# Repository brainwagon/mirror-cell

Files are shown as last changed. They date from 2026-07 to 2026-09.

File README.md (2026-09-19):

# Mirror Cell — 6" and 8"

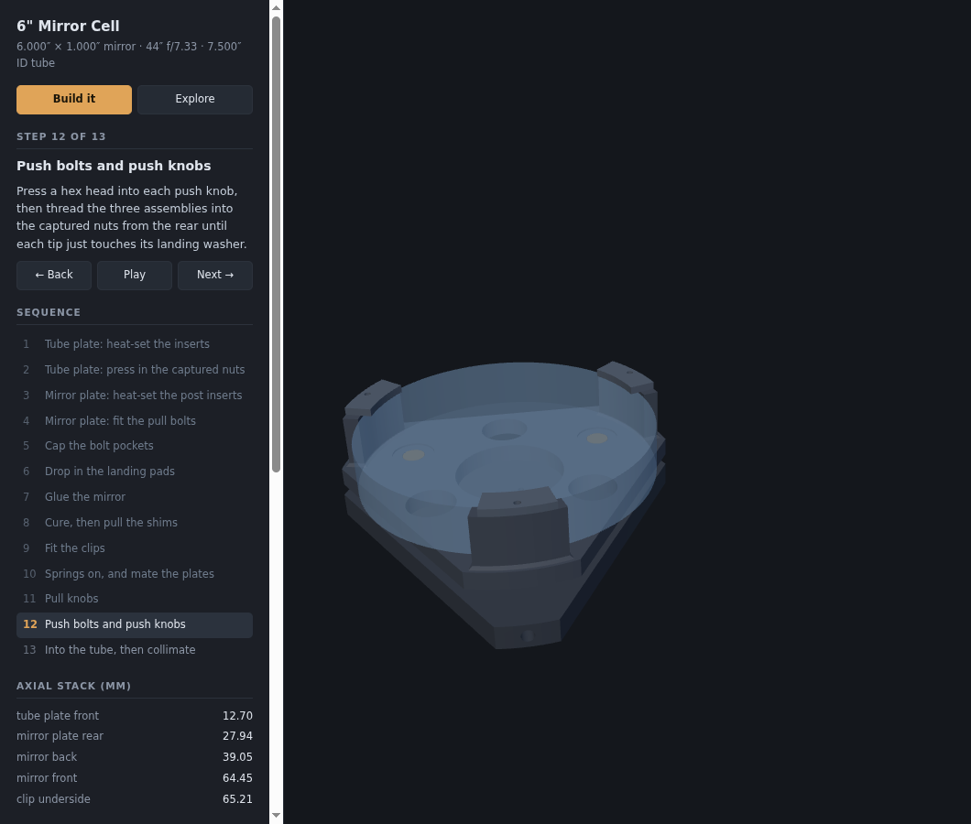
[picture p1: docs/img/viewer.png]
The assembly viewer, at step 12 of the 6" build sequence


A 3-point primary mirror cell — 3D printed in black ABS, assembled with 10-24 hardware by
default. The six collimation bolts (push and pull) can instead be **1/4-20** with
`--bolts 1/4-20`; the three tube-mount inserts stay 10-24 either way (see
[ADR-0004](./docs/adr/0004-collimation-hardware-is-a-config-option.md)). Two telescopes are
built from one model:

| | Mirror | Tube ID | Build | Buy list |
|---|---|---|---|---|
| **6"** (default) | 6.000" × 1.000", f/7.33 | 7.500" | `build/` | `BOM.md` |
| **8"** | 8.000" × 1.330" | 10.000" | `build-8/` | `BOM-8.md` |

The 6" is the original and the only one that has been printed and measured. The 8" is the
same cell with three numbers changed — see
[ADR-0003](./docs/adr/0003-the-8-inch-cell-is-the-same-cell-parameterised.md) for what
scales, what deliberately does not, and why it stops at two entries.

| File | Purpose |
|---|---|
| `HANDOFF.md` | **Start here when resuming** — state, blockers, and the traps |
| `BOM.md`, `BOM-8.md` | The buy lists, annotated. Generated — `--check` fails if one goes stale |
| `CONTEXT.md` | Glossary. Tube plate, Mirror plate, Station, Support point, Silicone dab, … |
| `mirror-cell-spec.md` | The design, its numbers, and the reasoning behind them (written for the 6") |
| `docs/adr/0001-…md` | Why the support points sit at 0.75R rather than the PLOP optimum |
| `docs/adr/0002-…md` | Why both rear controls are printed knobs clearing each other radially |
| `docs/adr/0003-…md` | Why the 8" cell is a config entry rather than a second design |
| `mirror_cell.py` | The model. All dimensions are named variables at the top |
| `test_coupon.py` | The ABS test coupons — the print that dials `FIT` |
| `TEST-COUPON.md` | How to print them, how to read them, where the answer goes |
| `index.html` | Assembly viewer — assembled/exploded, in the browser |
| `90866A011_….STEP` | Vendor wing-nut solid (McMaster). No longer part of the design — kept as ADR-0002's evidence |

## Build the geometry

```sh
python3 mirror_cell.py                # the 6" cell  -> build/,   BOM.md
python3 mirror_cell.py --aperture 8   # the 8" cell  -> build-8/, BOM-8.md
python3 mirror_cell.py --bolts 1/4-20 # 1/4-20 collimation bolts -> build-6-q20/
```

Runs 177 assertions **for the cell selected**, then writes `*.step`, `*.stl`, `3mf/*.3mf`
(geometry **and** that part's slicer settings), one dated zip of every part's STEP and
3MF — `mirror-cell-6in-YYYY-MM-DD.zip` — `assembly.json` and the bill of materials
— `bom.md`, `bom.csv`, and the committed snapshot at the top level (the build directories
are gitignored, so those snapshots are the copies the repo carries). If a BOM row changed,
the snapshot is rewritten and the run says which rows moved — **commit it**. To check
without writing anything:

```sh
python3 mirror_cell.py --check
python3 mirror_cell.py --aperture 8 --check
```

which verifies and then *refuses* a stale snapshot instead of repairing it. That is the CI
entry point, and the one to run on a fresh checkout — **run it for both apertures**, since
each one only checks the cell it was asked for.
The assertions encode the spec — the three gaps that must never close, both fastener
bearing floors, assembly clearances, spring travel, post placement, and printer bed fit.
**If a check fails, the geometry is wrong; do not print it.** Several real defects were
caught this way rather than at the print bed — including a version whose mirror could
never have been installed, because the clips were printed onto the posts.

If your blank is not the thickness the cell assumes (1.000" at 6", 1.330" at 8"), give it
in inches:

```sh
python3 mirror_cell.py --aperture 8 --mirror-thickness 1.375   # -> build-8-t1.375/
```

Everything that follows from the glass follows it — post height, the tube stub, the moving
mass the preload check weighs. A variant builds into its own directory, viewable as
`?cell=8-t1.375`, and writes no committed BOM snapshot, so the verified cells are never
touched. It is **refused** if the blank is floppier than the ones the 0.75R support
argument covers ([ADR-0003](./docs/adr/0003-the-8-inch-cell-is-the-same-cell-parameterised.md)):
an 8" blank 1" thick fails, at 3.16× the 6" cell's sag against the 1.34× argued for.

If you have 1/4-20 hardware instead of 10-24 for the collimation bolts:

```sh
python3 mirror_cell.py --bolts 1/4-20            # -> build-6-q20/
python3 mirror_cell.py --aperture 8 --bolts 1/4-20   # -> build-8-q20/
```

Only the six push/pull bolts, their six nuts, their pockets and holes change; the knobs and
the mirror plate grow to suit the larger hexes and the taller head, the springs open to
10.5 mm OD (with a longer free length to hold the preload) so they clear the 6.35 mm shank
([ADR-0005](./docs/adr/0005-the-1-4-20-cell-uses-a-larger-bore-spring.md)), and the
tube-mount inserts stay 10-24. It is a variant, so it builds into its own directory
(viewable as `?cell=6-q20`) and writes no committed BOM snapshot. **`FIT_PRESS` is measured
for 10-24 only** and is proportionally tighter on the larger 1/4-20 hex, so the fit coupon
refuses `--bolts 1/4-20` — measure a 1/4-20 pocket before printing the cell
([ADR-0004](./docs/adr/0004-collimation-hardware-is-a-config-option.md)).

Requires `build123d` (`pip install --user build123d`).

## View it

It is live at **<http://mvandewettering.com/mirror-cell/>** — the 6" cell, or
[`?cell=8`](http://mvandewettering.com/mirror-cell/?cell=8) for the 8". GitHub Actions
runs the exporter for both apertures **and both bolt sizes** on every push to `main` and
publishes the result (`.github/workflows/pages.yml`), because the build directories are
gitignored and so the site cannot be served from the repo as committed.

A **Mirror** switch (6″/8″) and a **Collimation bolts** switch (10-24/1/4-20) at the top of
the panel move between builds without leaving the page — each navigates to the matching
`?cell=` directory and keeps your place in the sequence. The mirror switch drops any
`--mirror-thickness` suffix (a blank is particular to its aperture); the bolt size carries
across. Both states are confirmed against `assembly.json`, so the switches always agree with
the geometry on screen.

To view a local build instead: the page fetches STLs, so it needs to be served over
HTTP — `file://` will not work.

```sh
python3 -m http.server 8018
# then open http://localhost:8018/              the 6" cell
#           http://localhost:8018/?cell=8       the 8" cell
#           http://localhost:8018/?cell=6-q20   the 6" cell, 1/4-20 collimation bolts
```

`?cell=8` reads `build-8/` instead of `build/`, and `?cell=6-q20` reads `build-6-q20/`, so
run the exporter for that combination first or the page has nothing to fetch. The coupons
are shared and always come from `build/`.

Two modes:

- **Build it** — steps through the 13-stage assembly sequence. Parts fly in as they are
  fitted, the mirror-plate sub-assembly is held clear while it is worked on, and the
  shims come back out at step 8. Each step carries its instructions, and the
  order-critical ones carry a caution. Prev/Next, a Play button, ←/→ keys, and a
  clickable step list. Linkable as `#step=7`.
- **Explore** — the explode slider and per-part visibility toggles.

The last step drops the cell into a **transparent stub of the sonotube** (7.750″ OD,
0.125″ wall, reaching 3.65″ behind the tube plate and 2″ above the mirror) with a 40 mm
fan on the rear face, so the finished assembly can be seen in context. Both are display
only and can be switched off in Explore. **The fan is a stand-in drawn in `fan()`,
not a vendor solid** — trust its envelope, not its details.

Under both is a **Downloads** panel. First **All printed parts**, one zip holding every
part's STEP and 3MF — named for the cell and the day it was built,
`mirror-cell-6in-2026-09-15.zip`, because once it has been mailed to somebody the filename
is all that says which cell it holds and how old it is. Its contents are taken from the
same download list the rows below it are drawn from, so it cannot quietly hold a different
set; the exporter writes it after the 3MFs have been verified and sweeps the cell's older
zips as it goes. Then the **annotated bill of materials** — MD or
CSV — which is not a hand-maintained table: `bom()` in `mirror_cell.py` counts the printed
quantities off the same instance lists the picture uses, reads every hardware dimension
out of the parameters, and carries one line of *why* for each row (machine screws not cap
screws, springs by geometry not by rate, fender washers on the outside). Assertions check
that it lists every printed part, agrees with the download list part for part, buys
exactly the nuts, washers, springs and screws the model draws, and leaves no row
unannotated. Below it is every printed part and both test coupons, each with its STEP, its
**3MF** and (smaller) its STL. The 3MF is the one to print: a solid in real units that
also carries that part's walls, top/bottom shells and infill, so it slices without being
dialled in. They ride as **per-object overrides** in `Metadata/model_settings.config`, an
Orca/Bambu-family convention rather than anything in the 3MF standard — the core spec has
no notion of a perimeter count — so in Cura and friends the file opens as plain geometry
and the settings are ignored. **Select your own process preset first**, at 0.2 mm layers:
the overrides sit on top of it and move only the part-specific keys, so your speeds,
accelerations and temperatures are the ones you chose, and they survive switching presets.
Layer height is deliberately *not* in the file — it has no per-object form, and the shell
counts are layer counts that only buy the intended thickness at 0.2 mm. `verify()` checks the settings data, and after writing, each
file is reopened and its config compared with what the model meant, because seven files
with no settings in them look exactly like seven correct ones from the outside. That list
is generated — printed parts from `assembly.json`, coupons from `coupons.json` — so it
cannot offer a file the exporter does not write, and an assertion checks that it names
every part in `PARTS` with the right quantity. The coupon rows appear once `test_coupon.py` has been
run; until then the panel says so. `build/` is gitignored, so the files are whatever your
last run produced.

Drag to orbit, scroll to zoom, right-drag to pan. The picture at the top of this file is
that page, on step 12 of the 6" sequence.

**The instructions are not written in the HTML.** `sequence()` in `mirror_cell.py` emits
them alongside the geometry, and assertions check that every step names a part that
actually exists and that the last step shows the finished cell. Instructions and parts
cannot drift apart.

three.js is vendored under `js/vendor/` (copied from `~/dob`); there is no CDN or network
dependency, and no STL loader — `parseSTL` reads build123d's binary STLs directly.

## One source of truth

Every position in the viewer comes from the selected cell's `assembly.json`, which
`mirror_cell.py` writes from the same variables that cut the geometry. No dimension is
typed into the JavaScript, so the picture cannot drift away from the parts — and the
same page draws either cell without knowing anything about apertures.

## Status

No cell part has been printed yet, but **both coupons have.** The fit coupon (2026-07-28)
gave 0.7–0.9 % measured shrink and put the captured nut on the 0.10 rung, so
`FIT_PRESS = 0.10`. The insert coupon (2026-07-29) passed on both 10-24 bores, the 3.05 mm
roof and the M3 bores in the rib, with the `insert_solid` modifiers in place —
`INSERT_BORE_D = 6.5` stands as drawn. **The tube plate is cleared to print.**

The mirror plate still waits on `FIT_SLIP = 0.20`, which is predicted from the shrink
rather than measured — one 10-24 hex bolt in row H of the coupon settles it. And the insert
coupon has not been *sectioned*, which is the only way to confirm the modifier put solid
material around the bore in the plastic rather than only in the file. See
[TEST-COUPON.md](./TEST-COUPON.md).

The rear end was reworked afterwards ([ADR-0002](./docs/adr/0002-both-rear-controls-are-printed-knobs.md)):
both controls are printed knobs that clear each other radially, the wing nut is gone, and
all six bolts are 10-24 × 1½″ machine screws by default — the same six can be 1/4-20 with
`--bolts 1/4-20` ([ADR-0004](./docs/adr/0004-collimation-hardware-is-a-config-option.md)),
which grows the knobs to Ø19.5 and the mirror plate to 10.1 mm. Print one pull knob and
press a nut into its 2.2 mm wall before committing to six. Plate and knob outlines are
functional but aesthetically provisional.

**Nothing of the 8″ cell has been printed at all.** Its 177 checks pass and it shares the
6″ cell's measured fits, so the coupon work carries over — but its tube plate is
237 × 207 mm on a 250 mm bed with only a 5 mm brim, and warp on a plate that size is the
one risk no assertion covers. Print that plate first.

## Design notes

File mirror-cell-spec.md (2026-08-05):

# 6" Mirror Cell — Design Spec

*Derived from a grilling session, 2026-07-28. This is the design for one specific
telescope: the 6" Newtonian originally built in the 1970s, being rebuilt with a 3D-printed
cell. Every number below is that cell's.*

*An **8.000" × 1.330"** variant was added later and is built from the same model by
`--aperture 8`. It is the same architecture, the same hardware and the same assertions,
with the mirror, tube, bolt circles, plate outlines and spring following from three
numbers — the derivation and its limits are in
[ADR-0003](./docs/adr/0003-the-8-inch-cell-is-the-same-cell-parameterised.md), and that is
where to look before assuming any figure on this page applies to it. What still holds for
both: §3 architecture, §5 the nominal-dimension convention, §6 compression everywhere, and
every tripwire in §11.*

Terminology is defined in [CONTEXT.md](./CONTEXT.md) and used strictly here.

---

## 1. The telescope this is for

| | |
|---|---|
| Mirror | 6.000" dia × 1.000" thick, 44" focal length (**f/7.33**), **2.3 lb** |
| Tube | Sonotube, 7.750" OD / **7.500" ID** |
| Related | `~/dob` (mount designer), `~/dob-6-project` (this scope's DXFs), `~/blip` (the FEA that settled the support radius) |

The mount project `~/dob` explicitly scopes out the mirror cell — its part inventory has no
cell at all. This project fills that hole.

## 2. Scope

**In scope**, all five jobs of a cell: axial support, lateral support, retention,
collimation, and the tube interface.

**Out of scope:** optical design (settled — 44" f/7.33); the mount (that's `~/dob`); any
aperture beyond the two the model builds. A 3-point cell is only valid to roughly 8–10",
so the 8" variant sits at the top of the range and **nothing larger belongs in this file** —
bigger mirrors need 6- or 9-point flotation, which is a different part family. A thin blank
is out of scope at *any* diameter: both cells' support radius depends on a full-thickness
mirror (§11, ADR-0001, ADR-0003).

## 3. Architecture

Two plates and three Stations.

- **Tube plate** — fixed to the sonotube, carries the collimation hardware, never touches
  the mirror.
- **Mirror plate** — floats on the collimation hardware, carries the mirror.
- **Station** — one of three positions at 90°/210°/330°. Each carries a Push bolt, a Pull
  bolt, a Support point, a Centering post and a Side clip, **all on one ray from the axis.**

Collimation is **push-pull with springs on the pull bolts** — the springs give compliance
while adjusting, the push bolts lock. This follows
[Stellafane](https://stellafane.org/tm/dob/ota/cell2.html) and matches the existing cell.

## 4. Geometry

**Radii.** Push bolts at **r = 1.500"**. Pull bolts at **r = 2.250" (0.75R)**. The three
Support points are **coaxial with the pull bolts** — see [ADR-0001](./docs/adr/0001-support-points-coaxial-with-pull-bolts.md).

**Axial stack**, measured from the Tube plate's rear face:

```
0.0000  tube plate rear face   ← both knobs live here
0.5000  tube plate front face
        ── 0.600" nominal spring gap ──
1.1000  mirror plate rear face  ← landing pads here
1.4750  mirror plate front face ← RTV wells here
1.5375  mirror back             (0.0625" bond)
2.5375  mirror front
2.5675  clip underside          (0.030" air gap)
```

The 0.600" gap is a **nominal, not a fixed dimension** — the Pull knobs set the real value.
The spring must neither coil-bind at minimum gap nor go slack at maximum. It cannot reach
either: the pull bolt's thread runs out **3.41 mm** past nominal, and the spring does not
go slack until **3.76 mm**, so the mechanism stops while the spring is still doing its job.
The push side has to follow the pull side anywhere it can go — at the widest reachable gap
the Push knob still stands **6.75 mm** off the plate rather than bottoming against it.

## 5. Parts

### Tube plate
7.500" OD triangle with three arc corners, flats at **60 mm** from the axis,
**0.500" thick**.

The flats are cut deep — 205 cm³ against 313 cm³ for a lightly-trimmed triangle, a **35%
saving on the largest part in the design**. That is safe because **the load path never
crosses a flat**: the collimation bolts sit on the station rays at r = 1.500" and 2.250",
and the tube screws are on those *same* rays at the arc corners, so the mirror's weight
travels radially outward along each arm. Material between stations carries torsion only,
and at ½" thick against ~2 lb per Station there is enormous margin. It also opens the back
of the cell further for mirror cooldown (§3) and leaves less large flat area to warp.

**The binding constraint is the corner tabs, not stiffness.** Those tabs carry the three
radial insert bores from which the entire cell hangs; a tab is
`2·(TP_FLAT_D − R/2)/cos 30°` wide at the rim, so cutting past ~53 mm eats into the bores.
At 60 mm the tab is 28.6 mm wide, leaving 11 mm of ABS each side.

- **Draw the OD at nominal 7.500"** and let ABS shrinkage supply the clearance. This is
  empirically confirmed by a test-fitted print, not calculated. **Do not pre-compensate
  any tube-referenced dimension** — mixing nominal and compensated conventions in one part
  is how this gets ruined.
- Center bore **1.500"** (changed from the prototype's 1.622" — see below), plus four M3
  holes on a 32 mm square: a **40 mm fan option, left unpopulated**. These cost nothing
  now and cannot be added later without pulling the mirror and reprinting.

  > **Changed from the prototype.** A 40 mm fan's screws sit on a 32 mm square, i.e. at
  > r = 22.63". Against a 1.622" bore that leaves a **0.43 mm web** — not a printable
  > feature. 1.500" restores a 1.98 mm web while still passing nearly the fan's full
  > 38 mm throat. Caught by the model's checks, not by inspection.
- Three **radial** 6.5 mm heat-set insert bores at mid-thickness, at the Stations.
- Push-bolt **hex nut pockets at r = 1.500", opening forward** (see §6).
- Pull-bolt clearance holes at r = 2.250", with spring seats on the front face.
- The prototype's six 0.5" edge scallops are **dropped**.

### Mirror plate
Triangle with three arc corners at **88.0 mm** radius, **0.375" thick**.

The outline is set by what it must contain, not by the tube. It has to hold the posts
(outer face at 84.96 mm) **plus the room their root chamfer needs outboard** — 3.04 mm of
margin. It was briefly trimmed to 86.0 to save material; that saved 1.7% and capped the
chamfer at 1.04 mm on the face that needs it most, so it went back to 88.0. Cheap plastic,
expensive stress riser.

Against a 95.25 mm tube-wall radius that is **6.9 mm of clearance at 3° of tilt**, and the
governing feature changes with angle: below ~5° the plate rim dominates, above it the clip
tops do, because tilt trades `r·cosθ` against `h·sinθ`.

- Pull-bolt **hex pockets at r = 2.250", opening forward, capped** (see below).
- **RTV wells** (22 mm dia) around each pocket to meter glue volume.
- **Landing-pad recesses** for **#4** washers on the rear face at r = 1.500". A #4 under a
  #10 bolt — see §7, the bore is the point.
- Centre bore **56 mm** — its *own* parameter, not the tube plate's. The tube plate's bore
  is set by the 40 mm fan screw circle; this one is limited by the landing pads (recess
  inner edge at 34.0 mm) and wants to be as open as possible so fan air actually reaches
  the back of the glass. Coupling the two would tie together constraints that have nothing
  to do with each other.
- Three **lightening holes** (r = 12.5 mm) at the mid-angles, between Stations.
- Three **Centering posts**, inner face at r = 3.030", 8 mm thick, each with an **M3
  heat-set insert** in its top face for a clip.
- A **1.5 mm × 45° chamfer round each post root.** The post is a cantilever wall and its
  root is a stress riser; worse, printed flat the root's tension is carried across
  **layer interfaces**, the weak direction in FDM. The critical face is the **outer** one:
  an upward load on a clip tips the post inward, putting the root's outer fibres in
  tension.

  Size is capped on both sides — outboard by the plate edge (3.04 mm of room at
  `MP_ARC_R` = 88.0), inboard by the mirror's 1.588 mm bond gap. **Inboard now binds:**
  the chamfer rises `c − 0.762` mm at the mirror rim, so 1.5 mm leaves 0.85 mm of air
  under the glass. It is built as a **loft**, not a tapered extrude — OCC's tapered prism
  fails on this profile above about 1 mm.

**Lightening the mirror plate works differently.** The tube-plate trick — cutting the
flats deeper — does *not* transfer: the posts span ±16° and reach r = 86.5, so they
already occupy the angles the flats would bite into, leaving only 2.7 mm of room in the
outline. The free material is in the middle and at the mid-angles instead, and taking it
gives **13.8%** (192.7 → 166.0 cc).

This is safe for the same reason as the tube plate, only more so: [ADR-0001](./docs/adr/0001-support-points-coaxial-with-pull-bolts.md)
made each silicone dab **coaxial with its pull bolt**, so the mirror's weight goes straight
into the bolt with *zero span*, and the push bolts are on the same rays. Between Stations
the plate only has to keep the three coplanar.

**The trap is sizing the holes so they merge into the bore.** At r = 18 on a 42 mm circle
the hole meets a 56 mm bore, the plate is cut clear through at every mid-angle, and the
three arms end up joined only by a 5 mm rim. It computes as a 20.9% saving and is
structurally worthless. Straps are held at **6 mm on both sides** and checked.

### Side clips (×3, separate parts)
**The clips cannot be integral, and this is a correctness constraint, not a preference.**
A clip reaching in to r = 71.2 mm leaves a 142.4 mm opening; the mirror is 152.4 mm. With
clips printed onto the posts the mirror could never be installed at all — it is 10 mm too
big to pass, in every direction, with only 2.35 mm of vertical slack under the clips
against a 25.4 mm blank, so it cannot be tilted in either.

Being separate also fixes a printing problem: integral, a clip is a 5.76 mm horizontal
overhang 37 mm up in the air, and the surface that would droop or need support is its
**underside — the 0.030" air gap**, one of the three gaps that must never close. Printed
flat as its own part, that face is a clean bed-facing surface.

Each clip bolts to a post top with a single **M3 cap screw**. Fitted after the mirror is
glued and cured.

### Pocket caps (×3, separate parts)
The pull bolt goes in from the **front** face, so its hex pocket must open forward — into
the same face the silicone dab sits on, since the dab is coaxial with the bolt
([ADR-0001](./docs/adr/0001-support-points-coaxial-with-pull-bolts.md)). That leaves a
hole in the middle of the RTV well. Without a cap the dab is laid over open air: silicone
runs down into the hex, the bond loses volume, its thickness stops being what the shims
say, and the bolt head is bonded in.

The cap is an **11.5 mm × 1.5 mm printed disc** dropped into a 12 mm counterbore, flush
with the well floor. It carries ~30% of the dab area, about **0.16 lb** per Station.

**It is deliberately not a precision fit.** The disc is 0.5 mm under its bore so it always
drops in, it overlaps its ledge by 1.02 mm so it cannot fall through onto the bolt head,
and it is **bedded in a spot of the same RTV** used for the dabs — which is already in
hand at that point in the sequence. An earlier version used a 10 mm bore, which left only
**0.27 mm of ledge at the hex corners**; in a material that shrinks 0.6–0.8% that part
either jams or drops through. Nothing about this cap should need dialling in.

### Printed shims (×3, separate parts)
0.0625" thick. Set the RTV bond thickness during cure, then pulled out. Replaces the
toothpicks used previously — same thickness, now repeatable.

### Push knobs (×3) and Pull knobs (×3)
Both rear controls are printed, each capturing its steel in a **hex pocket** — a form fit,
not friction, so neither can slip. The Push knob (Ø16 × 14) takes a bolt head and carries
torque only; it is **blind behind its pocket** — the shank leaves through the pocket's own
opening, so a clearance bore would be nothing but a hole out the back, and a head pressed
in is meant to stay. The Pull knob (Ø18 × 14) takes a plain 10-24 hex nut and **replaces the wing
nut**; its nut stands **0.4 mm proud** of the printed face so steel bears on the tube plate
and the ABS never does.

They sit on one Station ray 19.05 mm apart and clear each other **radially by 2.05 mm** —
unconditionally, unlike the axial escape this replaced, which depended on bolt length and
on where the adjusters were set. See
[ADR-0002](./docs/adr/0002-both-rear-controls-are-printed-knobs.md). The diameters are not
free: the split equalises the walls, because the Pull knob's nut is 11.11 mm across corners
against the Push knob's head at 9.28. Both walls land at ~2.2 mm after 12 flutes cut
1.2 mm deep.

A ½″ knurled thumb screw (e.g. Ondrives GPQ-23-3, Ø½″ head) drops into the Push knob's
envelope with 5.6 mm to spare, and is a valid alternate if you would rather buy than print
that end.

## 6. Why the nut pockets open forward

Work out the load direction. A Push bolt threaded in the Tube plate shoves the Mirror
plate forward, so its reaction drives the nut **rearward** — the nut needs plastic behind
it, so its pocket opens *forward*, into the gap. The same is true of anything threaded
into the Mirror plate.

This is why the Pull bolt is **reversed**: a hex head captured in the Mirror plate, shank
rearward through the spring, **nut on the outside**. Tension then loads a flat pocket
floor in **pure compression** — the one loading ABS handles without creeping — and nothing
that can loosen is trapped under the mirror.

**Every steel-to-plastic interface in this design is in compression.** That is not
incidental; ABS creeps under sustained tension, and a cell that creeps loses collimation
slowly, invisibly, over weeks. The Landing pads exist for the same reason: a bolt tip
bearing directly on ABS would emboss a dimple and walk the collimation.

**The pads are #4 washers, and that is the whole design of them.** They were #10 washers
for most of this project's life, which is the obvious choice and a useless one: a #10
washer's 0.2031" bore *is* free-fit clearance for a #10 bolt, so the push-bolt tip passed
through it with 0.166 mm to spare and landed on the plastic floor of the recess. The pad
sat there doing nothing while the bolt bore on ABS over 18 mm² — a *smaller* area than
the flat plate would have given it, so the recess actively made the thing it was meant to
prevent worse. A pad is defined by what it stops, and its bore must be **smaller than the
bolt's point**, not sized to the bolt.

The margin is thinner than it looks, because a machine screw's end is chamfered: taking a
conservative 0.85 × major diameter, the point is 4.10 mm, and the #4's 0.125" bore leaves
a **5.3 mm² contact annulus**. A #6 washer — the other obvious candidate, 0.156" bore —
leaves **0.9 mm²**, a 0.07 mm wide ring that is knife-edge contact on the bore rim, and
`verify()` rejects it. Do not "upsize" these pads.

Nothing caught this for the whole project because the only assertion touching the pads
proved that a pad *fits its recess*, which it always did. Two checks now assert what a pad
is for: the bore against the bolt point, and the contact annulus against the solids.

## 7. Hardware

This table is the *reasoning*; the shopping list is generated. `bom()` in `mirror_cell.py`
writes [BOM.md](./BOM.md) and `build/bom.csv` from the model's own parameters and instance
counts, annotated line by line, and the viewer offers both for download. Assertions tie it
to the geometry — it buys exactly the nuts, washers, springs and screws the model draws.

| Qty | Item |
|---|---|
| 6 | 10-24 **hex-head machine screws**, **all 1½"** — one type *and* one length throughout, and a ½" multiple |
| 6 | 10-24 hex nuts — three captured in the Tube plate, three in the Pull knobs |
| 3 | **#4** flat washers, 0.3125" OD × 0.125" bore (Landing pads) — a #4 under a #10 bolt |
| 3 | Compression springs — **0.9 mm wire × 9 mm OD × 20 mm free length, ≈ 13 lb/in** |
| 3 | #10 screws + **1" fender washers** (tube mount) |
| 3 | 10-24 heat-set inserts, 6.5 mm bore (tube mount) |
| 3 | **M3 heat-set inserts, 4.0 mm bore** (post tops, for the clips) |
| 3 | **M3 cap screws**, ~10 mm (clips) |
| — | Black ABS; RTV silicone |

**Machine screws, not cap screws.** A #10 hex *cap* screw carries an unthreaded shank about
19 mm long — exactly where the captured nut in the Tube plate needs thread. Machine screws
in this size are threaded to the head.

**Springs — do not buy a "telescope collimation spring kit."** Those are sized for cells
with no push bolts, where springs alone hold collimation; a typical ScopeStuff-style
primary spring computes to **~152 lb/in**, over ten times what this wants, and you would
never turn the Pull knobs. Buy by **geometry**, not by rate — listings publish wire
diameter and OD but rarely rate, and rate follows from `k = Gd⁴/8D³n`. Wire diameter
dominates (fourth power): a common assortment kit at 1.4 mm wire computes to ~57 lb/in,
still far too stiff.

At the 0.600" gap, 13 lb/in gives **1.92 lb preload per Station, 5.77 lb total** against
2.65 lb of mirror and plate — **2.18×**, so the Mirror plate stays seated against its stop
in any tube orientation while you adjust, and is still finger-turnable.

**A substitute that works: uxcell 1.0 mm wire × 9 mm OD × 20 mm, 304 stainless**
(Amazon `B0GFCR3MPW`, 10 pcs, checked 2026-07). The exact 0.9 mm spring above is awkward
to source; this one is stocked. Everything geometric is unchanged — same OD, so the
9.8 mm seat still clears; same free length, so the slack/thread-runout margins of §4 are
untouched; ID 7.0 mm still clears the #10 shank it rides on; solid height ~7.4 mm, still
far inside the coil-bind check. Only the rate moves: **≈ 18 lb/in**, giving **2.64 lb per
Station, 7.9 lb total, 2.99×** the moving assembly. Two effects partly cancel — 0.9 → 1.0
mm wire is 1.52× on `d⁴`, while 304 stainless has G ≈ 69 GPa against the ~79.6 GPa music
wire the 13 lb/in figure assumes. Net ≈ 1.4× the design preload.

Caveats. The Pull knobs turn ~40% stiffer; still finger-turnable, but check the feel on
first assembly rather than trusting the number. And no listing at this price publishes
active coil count, so the rate is a computed estimate, not a spec — across a plausible
4.5–6 coil spread it lands 16–21 lb/in (2.7–3.6×). That uncertainty is tolerable **only
because the error runs the safe way**: too stiff costs finger torque, too soft costs the
mirror plate its seat. Substitute upward in wire diameter, never downward — the same
vendor's 0.8 mm × 9 mm × 20 mm computes to ~6.8 lb/in and **1.14×**, below even the
1.31× regression described next, and at the fine-pitch end of its coil spread it does not
hold the assembly up at all.

**The spring's span is the gap *plus the seat*, and that is not a detail.** The seat is a
counterbore in the Tube plate's front face, so every millimetre of it lengthens the spring
and throws away preload. The figures above hold at the current **1.0 mm** seat. The seat
was 2.5 mm for a while, which quietly cost 40% of the preload — 1.16 lb per Station,
1.31× the moving assembly — and nothing caught it, because no assertion computed force
from geometry. `verify()` now does, so the number in this paragraph and the geometry
cannot drift apart again.

**Fender washers** matter. Statically the three tube screws see ~70 psi against cardboard
that's good for over 1000. The load case is **transport**: a 10 g knock puts ~700 psi on
the hole edge, cardboard crushes, holes go oval, and collimation is gone every time you
move the scope. A 1" fender washer spreads that ~15× and makes it a non-issue.

**The collimation range is a side effect of the bolt clearance, not a designed number.**
`BOLT_CLEAR_D` is 0.2031" — the stock free-fit clearance for a #10 screw, **0.333 mm
diametral, 0.166 mm per side.** Nothing was added for angular play, and the range that
falls out is what the cell has:

| | as drawn | as printed |
|---|---|---|
| Pull-bolt hole | 5.503 mm | **5.159 mm** |
| Tilt, **half-angle** | 3.27° | **1.62° = 97 arcmin** |
| Full swing between extremes | 6.54° | 3.24° |
| Travel at one Station | ±4.90 mm | **±2.42 mm** |
| Mirror edge | ±4.36 mm | ±2.16 mm |

**The right-hand column is the design; the left is scrap the printer never sees.** That is
the reverse of every other table here, and it is deliberate — `BOLT_CLEAR_D` is now a
*printed* dimension, and the hole is drawn oversize through `drawn_hole()` to land on it.
The as-drawn column is shown only so nobody re-derives the range from a caliper on the CAD.

The **Pull** bolt is the one that tilts in the Tube plate: its head is clamped flat against
the Mirror plate's 3.45 mm floor by spring tension, so its axis stays normal to the mirror
and the full mirror tilt appears at the Tube plate hole. The guiding length is **11.7 mm**
— the ½" plate less the 1.0 mm spring seat, which is Ø9.8 and constrains nothing. A
cylinder of diameter *d* tilted by θ through a hole of length *L* needs `d/cos θ + L·tan θ`.

> **This table read ±1.42° for a plate that had no range at all.** The first Tube plate
> drew these holes at 5.159 and printed them at **0.19" — the bolt's own major diameter**,
> zero clearance, discovered by hand during assembly. The model had applied linear shrink
> and nothing else; a small round hole also loses ~0.29 mm diametral to chord
> approximation and inner-perimeter over-extrusion (`HOLE_LOSS`, measured 2026-07-31),
> which is an offset rather than a percentage and does not appear on the flat-walled hex
> pockets. Every arithmetic step above was right and rested on an unstated assumption that
> a bolt fits the hole. `verify()` now states it.

The cone is symmetric, and all three bolts share the Mirror plate's normal, so every Pull
bolt tilts by the same angle whichever way the plate leans — the limit does not depend on
tilt direction. Nominal assembly sits at the centre of the cone. This is ample: one full
turn of a Pull knob is 42 arcmin, so two turns spans everything, and real collimation is
arcminutes. **The hole binds before the spring does** — the spring allows 3.76 mm at a
Station (2.51°) and the hole stops you at 2.42 mm. That ordering is the safe one and is
asserted: jamming a bolt is a hard stop and harmless, while a slack spring at full tilt
costs the Mirror plate its seat. It is the same argument as `thread_range < spring_range`.
§11 records the whole bracket as a decision.

> **The lateral freedom of the Mirror plate is load-bearing, and it does not look it.**
> Over 1.62° a Pull bolt anchored at the Mirror plate swings **0.60 mm** sideways at the
> Tube plate, against 0.17 mm of slop per side. The plate therefore does **not** tilt about
> a fixed point: it translates ~0.30 mm sideways so the three bolts can centre. That works
> only because nothing laterally registers it — it floats on three springs, three Push tips
> bearing on washers with 1.92 mm of radial room, and three Pull bolts. A 0.30 mm mirror
> decentre is optically nothing at f/7.33. **Any future centring feature between the two
> plates would collapse the tilt range, and no assertion would catch it.**

## 8. The three gaps that must never close

| Gap | Value | Guards against |
|---|---|---|
| Centering post → mirror edge | **0.030" radial** | Cold-night pinch |
| Clip → mirror front face | **0.030" axial** | Contact stress → astigmatism |
| RTV bond thickness | **0.0625"** | Mirror bottoming onto plastic |

ABS moves ~90 ppm/°C against glass at 3–9. Cooling from a 22 °C room to a −8 °C night
contracts the plate ~0.016" on diameter while the glass barely moves — **~0.007" of radial
squeeze**. Posts fitted snugly at room temperature would grip the mirror on exactly the
coldest, best-seeing nights.

The model states this as a **solid-vs-solid test**, not as dimensions: the mirror's
volume is intersected with the mirror plate and with each clip, and both must be empty.
That covers the posts, the root chamfer and the clips in one statement, and cannot be
fooled by a feature nobody thought to measure.

These gaps are printed, specified and non-adjustable. **Closing one is a defect, not a
tighter assembly.** The failure they prevent is invisible: a pinched or bottomed mirror
looks correct, passes daylight inspection, and only shows as astigmatism on nights good
enough to notice — by which point it is glued down.

Bond thickness was checked rather than assumed. Differential contraction shears the dab,
and force on the glass scales as 1/thickness: 1.5 lb per dab at 0.125", **3.0 lb at
0.0625"**, 6.2 lb at 0.030". RTV takes >100% shear strain elastically, so 9.4% is nowhere
near a limit, and the load is *in-plane* — the least harmful direction. Thinner is
simultaneously better for axial sag and collimation retention, which is why 0.0625" wins
over the 0.125" first proposed.

## 9. Assembly notes

- **Drill the tube in situ**, using the Tube plate's own insert bores as the drill guide,
  with the plate held at the depth that reaches focus. The Tube plate's axial position is
  what sets mirror-to-focuser distance; nothing else constrains it.
- Install the push-bolt nuts **before** the Mirror plate goes on. Once a bolt is threaded
  in, its nut is captive permanently.
- **Order matters at the mirror: posts, then glass, then clips.** Drop the mirror in past
  the Centering posts (1.52 mm of slip), shim it, let the RTV cure, pull the shims, and
  only then bolt the Side clips on. There is no way to fit the mirror with clips in place.
- Hex pocket clearances **must be dialled on an ABS test coupon** before printing either
  plate — ABS shrinks 0.6–0.8% and nominal dimensions will not fit.
- Press each Pull knob's nut in until it stands 0.4 mm proud of the printed face, not
  flush. If the printed face reaches the plate, ABS turns on ABS under tension and creeps.
- Collimate by backing off the Push knobs, setting tilt with the Pull knobs, then snugging
  the Push knobs. The cell is deliberately *soft* while adjusting and stiff once locked.

## 10. Open items

- ~~Mirror plate thickness~~ — **resolved at 0.375"**. The model checks the stack: RTV
  well 1.0 + cap 1.5 + hex pocket 3.575 leaves a **3.45 mm floor** for the pull bolt head
  to bear on. This is also why there is **no spring seat on the mirror plate's rear face**
  — cutting one would have left 0.95 mm of ABS under that floor. The spring is located by
  its tube-plate seat and the bolt shank, and bears on the flat face.
- ~~Center bore~~ — **resolved at 1.500"**, see §5.
- ~~Hex pocket clearance~~ — **measured on `coupon_fit`, 2026-07-28**: `FIT_PRESS = 0.10`
  (captured nut and both knobs; the nut seats flat, will not rotate, no whitening) at
  0.7–0.9% linear shrink. `FIT_SLIP = 0.20` for the Mirror plate's pull-bolt head is
  **predicted from that shrink, not measured** — no 10-24 hex head was on hand. See
  [TEST-COUPON.md](./TEST-COUPON.md).
- ~~Exact bolt lengths~~ — **resolved: all six are 1½".** Formerly 2", a length that
  existed only to drop a Ø30 knob below a wing nut it overlapped by 7.06 mm radially. Both
  rear controls are printed knobs now and clear each other *radially*, so nothing needs
  length to escape anything — see
  [ADR-0002](./docs/adr/0002-both-rear-controls-are-printed-knobs.md). 1½" is a ½" multiple,
  which is what shops stock.
- Knob and plate outline shapes — aesthetic, provisional. The knobs are functional at Ø16
  and Ø18 but grip is the thing ADR-0002 gave up, and **height is the free dimension** now
  that nothing lives behind them.
- **Untested: the hex press fit in a 2.2 mm knob wall.** `FIT_PRESS` was measured in a
  6 mm coupon plate with material all around it. Print one Pull knob and press a nut into
  it before committing to six.
- **No fan is bought.** The mounting holes are real, and the viewer now shows a 40 × 40 ×
  10 mm fan on the 32 mm pattern — but that solid is a **stand-in drawn here**, not a
  vendor model, and it is the only item in the repo that is neither measured nor derived
  from the design's own dimensions. What the checks use is the envelope, which every 40 mm
  fan shares: the corners clear the Push knobs by 3.06 mm and the throat passes the 1.500"
  centre bore. Swap in a real solid before trusting anything finer than that.
- **The tube stub is display only.** 7.500" ID × 0.125" wall, from 3.65" rearward of the
  Tube plate's mid-plane to 2" above the mirror's face. The tube belongs to the telescope,
  not to this design, but every clearance argument here is made against it.

## 11. Load-bearing decisions, and what would overturn them

- **All steel-to-plastic interfaces in compression** (§6). If a future revision introduces
  a fastener in sustained tension against ABS, the creep argument is broken and
  collimation stability is no longer predicted.
- **Support radius chosen mechanically, not optically** ([ADR-0001](./docs/adr/0001-support-points-coaxial-with-pull-bolts.md)).
  Valid only because the mirror is full-thickness. **Tripwire:** a thin or larger blank
  makes support placement matter again, and this design should not be reused for one. The
  8" cell clears this tripwire *only* because its blank is 1.330" — the same 6:1 ratio as
  the 6" one, so it deflects 1.33× as much, which is still nothing. An 8" mirror 1" thick
  would not clear it ([ADR-0003](./docs/adr/0003-the-8-inch-cell-is-the-same-cell-parameterised.md)).
- **Nominal-dimension convention against the tube** (§5), confirmed by a real test fit —
  not by calculation. Re-verify if the filament or printer changes.
- **Rear clearance is radial, not axial** ([ADR-0002](./docs/adr/0002-both-rear-controls-are-printed-knobs.md)).
  It holds for any bolt length and any adjuster position, which the axial arrangement it
  replaced did not. **Tripwire:** enlarging either knob, or putting any purchased part back
  on the pull station, spends the 2.05 mm that makes it true — and a wing nut spends all of
  it and 5 mm besides.
- **Spring preload is computed from geometry, never typed in** (§7). It is the product of
  free length, rate, gap *and seat depth*, and it has already been broken once by a change
  to the seat that looked unrelated.
- **The collimation range is inherited from a stock #10 free-fit clearance** (§7): ±1.62°
  as printed, from 0.166 mm per side over an 11.7 mm guiding length. Nobody chose it, and
  it is the *tightest* limit in the adjustment chain — the spring would allow 2.51°.
  **Tripwires:** a thicker Tube plate, a deeper spring seat (which shortens the guide and
  would *increase* range while costing preload), or any tightening of `BOLT_CLEAR_D` moves
  it directly — and all three are now checked. `pull_bolt_tilt()` computes the budget as
  printed, and `verify()` brackets it: at least `TILT_NEEDED` (0.5°, the range the cell must
  *provide*), under `TILT_MAX` (3°, the envelope the tube-wall swing check assumes), and
  below the angle at which the spring goes slack. `TILT_MAX` stays a fixed 3° and is
  deliberately **not** derived from the holes, so that a change opening the range up fails
  the check instead of quietly widening the envelope with it.
- **Round holes are drawn oversize; every other dimension is drawn nominal** (§7). The
  nominal-dimension convention (§5) holds for outside profiles and for flat-walled pockets,
  and it is *wrong* for small round holes, which lose a further ~0.29 mm of diameter to the
  slicer. `HOLE_LOSS` carries that, `drawn_hole()` applies it, and `BOLT_CLEAR_D` is
  therefore the only dimension in this design that means *as printed*. **Tripwires:** a new
  bolt hole added with a bare `Circle(d/2)` rather than through `drawn_hole()` — the
  fit-at-all assertion in `verify()` only covers the two named diameters; and a change of
  nozzle, profile, or slicer, which moves `HOLE_LOSS` and is worth one coupon before
  committing a plate to the bed.
- **The Mirror plate is laterally unregistered, and the tilt range depends on it** (§7).
  Tilting needs ~0.30 mm of sideways plate movement, because a Pull bolt swings 0.60 mm at
  the Tube plate against 0.17 mm of slop per side. **Tripwire:** any pilot, boss, or
  centring feature between the two plates — the sort of thing that reads as an improvement
  — would collapse the tilt range, and nothing in the model would notice.

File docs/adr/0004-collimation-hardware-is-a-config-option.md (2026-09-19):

# The collimation hardware is a config option; the tube mounts are not

The six push/pull bolts and their nuts are now selected by `--bolts` (`10-24`, the default,
or `1/4-20`), and every dimension they touch is derived from that choice. The three radial
tube-mount heat-set inserts and the #10 screws into them do **not** switch, and that split
is the whole decision.

## Why the tube mounts stay 10-24

A ruthex 1/4-20 insert is **8.7 mm across** (`RX-1/4"-20x12.7`) and wants a **3.3 mm** wall.
The tube plate is 0.500" (12.7 mm) thick, so the roof over the seated insert would be
`(12.7 − 8.7)/2 = 2.0 mm` — well under ruthex's minimum. Giving it the wall it asks for
means a 0.625" plate, and the plate's thickness is not free: ADR-0002 pins it to the pull
bolt's thread range. Thickening it re-opens the axial stack, the spring span and both bolt
lengths, for a screw that carries no adjustment and sees a static load. So the tube mounts
stay 10-24, and the model says so in three places rather than leaving it to be inferred.

## What does follow the collimation fastener

The 1/4-20 nut and head are both **7/16" across flats**, against 3/8" and 5/16" at 10-24.
Nothing downstream is typed; each follows:

- **Knob diameters** are the smallest that leave `KNOB_WALL_MIN` (2.0 mm) of material at a
  flute over the hex they capture, rounded up to 0.5 mm. At 10-24 this reproduces the
  16/18 the cell has always had, bit for bit; at 1/4-20 both knobs come out **19.5**.
- **The knob budget** — the radial gap between the push and pull circles (ADR-0002) — grows
  from 0.750" to **0.860"**. 0.860" is not arbitrary: it is the widest the push circle can
  go inboard before the landing pad eats the strap to the mirror plate's centre bore, which
  is the binding constraint at 6". The push circle moves in, and `verify()` checks both the
  knob-to-knob gap and the pad-to-bore strap.
- **The cap counterbore** opens from 12 to **16 mm**, because a 1/4-20 head is 12.95 mm
  across corners and has to pass through it during assembly, leaving a ledge the cap cannot
  fall past.
- **The mirror plate thickens** from 0.375" to **10.1 mm**. The 1/4-20 head is 0.8 mm taller
  and cuts a deeper pocket; the floor under it carries the mirror's weight and the spring's
  sustained preload, so the plate grows to keep `MP_FLOOR_MIN` (3.2 mm). The 6" cell's
  0.375" already clears it, so its plate does not move.
- **The clearance and pass-through holes** come from the bolt's own `clear` and `pass_d`
  figures, still drawn through `drawn_hole()` so they print at the size the bolt finds.
- **The spring** is overridden per aperture, because the spring rides on the shank and a
  6.35 mm 1/4-20 needs a larger coil bore than the 9 mm springs give. See
  [ADR-0005](./0005-the-1-4-20-cell-uses-a-larger-bore-spring.md).

## Consequences

- **`FIT_PRESS` is not re-measured for 1/4-20, and cannot be.** It is an *added* across-flats
  clearance, and the clearance a nut actually sees is `fit·(1−S) − AF·S`: the same 0.10 mm
  leaves ≈0.023 mm at 10-24 but ≈0.010 mm at 1/4-20, i.e. proportionally tighter. The fit
  coupon is laid out around the 10-24 hexes and **refuses `--bolts 1/4-20`** rather than
  emit a gauge that no longer measures the right thing. A 1/4-20 cell wants a purpose-built
  coupon before its pockets are trusted — the same open item `FIT_SLIP` was.
- The 1/4-20 variant builds to `build-<ap>-q20/` (e.g. `build-6-q20/`) and, like a thickness
  variant, has no committed BOM snapshot; `build/bom.md` is still written. The viewer opens
  it as `?cell=6-q20`.
- The fan's clearance to the push knobs is now a **solid-vs-solid** check. The old radial
  comparison of the fan corner against the knob ring reads as a collision at 1/4-20 even
  though the two occupy different z-bands, and it would miss a real one from a shorter push
  bolt.
- A **spring-vs-bolt** check is added: the spring rides on the pull bolt shank, so its coil
  bore must clear the bolt. At 10-24 this was true by luck (4.83 mm in ~7.1); at 1/4-20 it
  is 6.35 mm in the same 7.0–7.2 mm bore, and it is now asserted.
- **Reversible.** 10-24 remains the default and its geometry is bit-identical: every derived
  value reproduces the constant it replaced.

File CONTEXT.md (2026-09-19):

# Context: Mirror Cell

A 3-point primary mirror cell for a 6" Newtonian, 3D printed, assembled with 10-24
hardware (the six collimation bolts can be 1/4-20 instead — see ADR-0004 — but the three
tube-mount inserts are 10-24 in every build). Lives in the telescope built by `~/dob` /
`~/dob-6-project` (7.75" OD sonotube).

This file is a glossary. It holds terms, not dimensions, decisions, or construction
details.

## Glossary

### Tube plate
The fixed plate. Attaches to the sonotube and does not move relative to it. Carries the
collimation hardware. Does not touch the mirror.

Not "back plate" — that name has been used for both plates and is banned here.

### Mirror plate
The floating plate. Carries the mirror on its front face and rides on the collimation
hardware. Its position and tilt relative to the Tube plate is what collimation adjusts.

### Support point
One of the three locations where the Mirror plate bears the weight of the mirror. Three
of them, 120° apart, all at the same radius from the optical axis. Distinct from the
collimation bolts, which are at a different (larger) radius — the two sets of three
points are not the same three points and must never be conflated.

### Silicone dab
The compliant bond at a Support point: a blob of RTV between the Mirror plate and the
back of the mirror. It is simultaneously the axial support, the lateral restraint, and
the primary retention. Its compliance is functional, not incidental — it decouples the
glass from the much larger thermal expansion of the printed plate.

### Push bolt
A collimation bolt bearing against the Mirror plate, pushing it away from the Tube plate.
Snugged after adjustment; this is what locks collimation.

### Pull bolt
A collimation bolt drawing the Mirror plate toward the Tube plate, with a spring in
compression between the plates. The spring provides the compliance that makes adjustment
continuous; the Pull bolt sets the working point.

### Side clip
A retainer overhanging the front edge of the mirror. Drop-insurance only — in normal
operation it carries no load, because the Silicone dabs do. Not to be described as
"lateral support".

### Station
One of the three angular positions, 120° apart, at which the cell does all of its work.
A single Station comprises a Push bolt and its Push knob, a Pull bolt and its Pull knob,
a Support point, a Centering post and a Side clip. Saying "the three stations" is preferred to enumerating the hardware,
because everything at a Station shares one ray from the optical axis.

### Centering post
An upstand at a Station that locates the mirror concentric with the Mirror plate during
glue-up. It is a locating feature, never a clamping one: it stands off the glass by a
deliberate clearance so that differential thermal contraction can never let it grip.
Carries the Side clip.

### Landing pad
The steel washer let into the Mirror plate where a Push bolt bears on it. Exists so that
no steel fastener ever contacts plastic at a point — the load is spread over a face, and
the contact is steel-on-steel.

### Push knob
The printed knob at the user-facing end of a Push bolt. Captures the bolt's hex head in a
hex pocket — a form fit, not friction — and carries torque only, never axial load.

### Pull knob
The printed knob at the user-facing end of a Pull bolt, which is also its nut: it captures
a plain hex nut in a hex pocket, and the nut stands slightly proud of the printed face so
that steel, never ABS, bears on the Tube plate. Replaced a wing nut.

Not "Collimation knob" — that name meant only the push-side knob and there are two knobs
now, so it is banned here alongside "back plate".

## Standing rule: clearance is a feature

Three separate places in this design deliberately do *not* touch the glass — the Side
clips, the Centering posts, and (via the Silicone dabs) the Mirror plate itself. In each
case the gap is specified, printed, and non-adjustable. A gap here is never slop to be
taken up during assembly; closing one is a defect, because a pinched mirror is an
astigmatic mirror. The printed part expands and contracts roughly ten times as much as
the glass does, so every gap must survive the coldest night you will ever observe on.

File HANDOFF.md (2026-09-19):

# Handoff — 6" mirror cell

Written 2026-07-28. State of play, what is settled, what is not, and where the traps are.
Read [README.md](./README.md) for how to run things, [mirror-cell-spec.md](./mirror-cell-spec.md)
for the design and its reasoning, [CONTEXT.md](./CONTEXT.md) for vocabulary.

Under git as of 2026-07-31 (16 commits; head `fa302cc`).

## Where it stands

Design is complete and internally consistent. **177 assertions pass for each cell** (plus
103 in `test_coupon.py`). Two coupons have been printed and read; no cell part has, in
either aperture.

```sh
cd ~/mirror-cell
python3 mirror_cell.py            # verify + export build/*.step, *.stl, assembly.json, bom.md
python3 mirror_cell.py --check    # verify only; refuses a stale BOM.md, writes nothing
python3 mirror_cell.py --aperture 8 --check   # the same, for the 8" cell
python3 -m http.server 8018       # then open http://localhost:8018/  (?cell=8 for the 8")
```

## There are two cells now

`--aperture 8` builds an **8.000" × 1.330" mirror in a 10.000" ID tube** from the same
file, into `build-8/` and `BOM-8.md`. It is the same cell with three numbers changed:
[ADR-0003](./docs/adr/0003-the-8-inch-cell-is-the-same-cell-parameterised.md) has the
full derivation. Both cells pass all 177 checks. **Everything below this section is about
the 6" cell** unless it says otherwise — it is the one that has been printed and measured,
and the 8" inherits all of its measured fits because every fastener is identical.

Three things are worth knowing before touching either:

- **`CELLS` at the top of `mirror_cell.py` is the only place the two differ.** Mirror
  diameter, mirror thickness, tube ID, the spring, the expected moving mass and the brim.
  Everything else is derived or is hardware. Do not add a per-aperture number anywhere
  else in the file. The one exception is `--mirror-thickness` (inches), which replaces
  the entry's `mirror_t` for a blank that is not the assumed one. It builds into
  `build-<aperture>-t<thickness>/` with no committed BOM snapshot. A check refuses any
  blank that sags more than the CELLS blanks do (R⁴/t³), because that is as far as
  ADR-0003's 0.75R argument goes.
- **The 8" spring is a different part** — 1.0 mm wire × 9 mm OD × **25 mm** free length,
  ~12 lb/in, giving 4.14 lb per station. The 6" spring fails the preload check at 8" and
  should: the glass goes 1089 → 2574 g. The force is bought with length rather than rate
  so the knob torque stays where it was.
- **The 8" tube plate is 237 × 207 mm on a 250 mm bed.** It fits with a **5 mm** brim and
  not the 8–10 mm this page recommends everywhere else. That is now in the bed-fit
  assertion rather than a note. Warp on a plate that size is the one risk nothing in
  `verify()` can catch — see the traps.

**The tube-screw inserts are ruthex RX-10-24x9.5**, and the model now carries their
published numbers (`INSERT_OD`, `INSERT_HOLE_D`, `INSERT_MIN_WALL`, `INSERT_L`) because
assertions depend on them. The 6.5 mm bore is drawn nominal and shrinks onto ruthex's
6.4 mm recommended hole — **do not compensate it**. The tight dimension is the roof over
the seated insert: **2.80 mm against a 2.6 mm minimum**, and it is measured over the
7.1 mm insert, not the 6.5 mm bore it melts into, which would flatter it at 3.10 mm.

## The collimation hardware is selectable now

`--bolts 1/4-20` builds the same cell with 1/4-20 push/pull bolts instead of 10-24, into
`build-<ap>-q20/`. The `BOLTS` dict at the top of `mirror_cell.py` is the only place the
two differ; everything the fastener touches is derived from it.
[ADR-0004](./docs/adr/0004-collimation-hardware-is-a-config-option.md) has the full
derivation. The viewer's **Mirror** (6″/8″) and **Collimation bolts** (10-24/1/4-20)
switches move between the builds without leaving the page — each navigates to the matching
`?cell=`, keeping the step; the mirror switch drops any `--mirror-thickness` suffix. The CI
builds all four aperture/bolt combinations so the published site can offer them. Three
things to know:

- **The tube-mount inserts do NOT switch and must not.** A ruthex 1/4-20 insert is 8.7 mm
  across and needs a 3.3 mm wall; the 0.500" tube plate gives 2.0 mm. Giving it the wall
  means a 0.625" plate, which re-opens the axial stack (ADR-0002) for a screw that carries
  no adjustment.
- **The derived parts reproduce the 10-24 cell bit for bit** — knob diameters 16/18, budget
  0.750", cap bore 12.0, plate 0.375". If a change here moves those, it is a bug.
- **The spring is a different part too** — 10.5 mm OD, and a longer free length to hold the
  preload the softer rate costs (6" 23 mm, 8" 31 mm). The 9 mm springs only cleared the
  6.35 mm shank by 0.33–0.43 mm/side, which the leaning pull bolt's ~0.55 mm of sway
  exceeds. See [ADR-0005](./docs/adr/0005-the-1-4-20-cell-uses-a-larger-bore-spring.md).
- **`FIT_PRESS` is unverified for 1/4-20, and `test_coupon.py` refuses to run for it.** The
  fit is an *added* across-flats clearance, and the clearance the nut sees is
  `fit·(1−S) − AF·S`, so 0.10 leaves ≈0.023 mm at 10-24 but ≈0.010 mm at 1/4-20. A 1/4-20
  cell needs its own coupon before its pockets are trusted. **This is the 1/4-20 variant's
  blocking unknown**, exactly as `FIT_SLIP` was for the mirror plate.

All four builds (6"/8" × 10-24/1/4-20) pass the same 177 checks. The two added checks are a
spring-vs-bolt shank clearance (now against the shank's sway at full tilt, not a static
0.2 mm) and a solid-vs-solid fan/push-knob test (the old radial fan comparison read as a
collision at 1/4-20 even though the parts occupy different z-bands).

| Part | Qty | Volume | Notes |
|---|---|---|---|
| tube_plate | 1 | 204.7 cc | biggest print, 5½–7 h (measured; see slicer settings) |
| mirror_plate | 1 | 166.4 cc | posts + root chamfer integral |
| clip | 3 | 1.8 cc | separate — see traps |
| push_knob | 3 | 2.1 cc | captures a hex head |
| pull_knob | 3 | 2.5 cc | captures a hex NUT — this is the ex-wing-nut |
| pocket_cap | 3 | 0.16 cc | bedded in RTV, loose fit |
| shim | 3 | 0.57 cc | assembly aid, removed after cure |

**The buy list is generated.** [BOM.md](./BOM.md) — also `build/bom.csv`, and a download
button in the viewer — is written by `bom()` from the model's own numbers, with a line of
reasoning on every row. Take that to the shop rather than the summary below, which is here
only so this page reads as a whole (all six collimation bolts can be 1/4-20 instead — see
`--bolts`): 6 × 10-24 × 1½" hex-head **machine screws** (not cap screws — see spec §7) ·
6 × 10-24 hex nuts · 3 × **#4** washers (landing pads — see traps) · 3 springs (0.9 mm wire × 9 mm OD × 20 mm FL
≈ 13 lb/in; **10.5 mm OD × 23 mm** at 1/4-20 — see ADR-0005) · 3 × 10-24 heat-set inserts ·
3 × M3 inserts + M3 cap screws · 3 × #10 screws + 1" fender washers · black ABS · RTV
silicone.

## The print blocker, mostly cleared

`FIT` was a 0.25 mm placeholder for hex-pocket clearance, unverifiable by any assertion.
**`coupon_fit` has now been printed and read** (2026-07-28): on the **0.10** rung the 10-24
nut seats flat, will not rotate by hand, and leaves no stress whitening in the wall —
all three acceptance criteria. The gauge outline measured 3.91″ × 1.95″ against a drawn
3.937″ × 1.969″ — **0.7–0.9 % linear shrink**, inside the band the design assumed. The
model now carries `FIT_PRESS = 0.10` (captured nuts and both knobs) and `FIT_SLIP = 0.20`
(pull-bolt head), passed explicitly at every `hex_prism()` call site.

**The tube plate is printable, and now fully cleared to print.** Its only hex pocket is the
nut pocket, and that number is measured. **`coupon_insert` was printed and read on
2026-07-29 and passed** — both 10-24 inserts seated, the 3.05 mm roof held, the M3 bores in
the rib held. `INSERT_BORE_D = 6.5` stands as drawn; the 6.6 rung was not needed, which is
the good outcome, since 6.6 prints 0.147 mm off ruthex's recommended hole and fails the bore
assertion. That was also the first print carrying the `insert_solid` modifiers, so the
reinforcement scheme is confirmed in practice and not only in the file.

One thing deliberately left: **the coupon was not sectioned.** Breaking a bore open is the
only way to confirm the 100 % region really materialised around it rather than leaving
gyroid against the insert — which is what the minimum-wall assertion assumes. Cheap, and
worth doing before the plate rather than after — that print is 5½–7 h.

**The mirror plate is not.** `FIT_SLIP` is predicted from the measured shrink, not
measured: no 10-24 hex bolt was on hand. One bolt in row H of the coupon settles it, and
six are on the buy list anyway. Full working in [TEST-COUPON.md](./TEST-COUPON.md), which
also has the slicer settings and what is still unread on the coupon (cap disc, landing
pads, spring seat).

Everything else that could have needed dialling in was deliberately engineered out — the
pocket caps became a loose fit bedded in RTV precisely for this reason.

**One new unknown, added deliberately.** `FIT_PRESS` was measured in a 6 mm coupon plate
with material all around the pocket. Both knobs now put that pocket inside a **2.2 mm
wall**, where a press can bulge the wall instead of gripping. Print **one pull knob**
(~2.5 cc, ~15 min) and press a nut into it before committing to six. If it bulges, the fix
is diameter.

## The rear end was reworked, 2026-07-28

See [ADR-0002](./docs/adr/0002-both-rear-controls-are-printed-knobs.md). Both rear controls
are printed knobs — push Ø16, pull Ø18 capturing a plain hex nut — clearing each other
**radially by 2.05 mm** instead of the old axial escape, which depended on bolt length *and
on where the adjusters were set*. Consequences: the wing nut is gone, all six bolts are
**10-24 × 1½" machine screws** (one length, a ½" multiple), six identical hex nuts, and
rear stack-out falls from 36.9 mm to 24.2 mm.

Grip is what this cost: a Ø18 fluted ABS knob is worse with cold fingers than a 0.875"
steel wing nut, on the control you turn in the dark. Height is the free dimension now —
nothing lives behind the knobs — so make them **taller before wider** if it disappoints.
Wider spends the 2.05 mm the whole scheme rests on.

**The spring preload was wrong and is fixed.** `SPRING_SEAT_DEPTH` had grown from 1.0 to
2.5 mm, and the seat is part of the spring's span, so it silently threw away 40% of the
preload: 1.16 lb per station against the 1.9 lb §7 claimed. Back to 1.0 mm → 1.92 lb per
station, 5.77 lb total, 2.18× the moving assembly. `verify()` now computes preload from
geometry, and `assembly.json` draws the spring from the seat bottom rather than the plate
face, which was hiding 2.5 mm of its length in the viewer.

## Suggested slicer settings

These live in `PRINT` in `mirror_cell.py` as **values, not prose** — the sentence in the
BOM is generated from them — and they are also written into the parts themselves:
`build/3mf/<part>.3mf` carries walls, top/bottom shells, infill density and pattern, so
opening one in AnycubicSlicerNext or OrcaSlicer needs no dialling in. This table is the
same data, kept here because it is what you scan before a print. **Change `PRINT`, not
this table.**

**Select your own process preset first, at 0.2 mm layers, then open the 3MF.** The
settings are **per-object overrides** (`Metadata/model_settings.config` in the zip), an
Orca/Bambu-family convention and *not* part of the 3MF standard — the core spec has no
notion of a perimeter count, so these open as plain geometry in Cura and other slicers.
Overrides overlay the selected preset, so your speeds, accelerations and temperatures are
untouched and they survive switching presets. Only the part-specific keys are in the file;
the machine settings below are ranges, so they stay prose here and are dialled in by hand.

**`tube_plate.3mf` also carries three modifier blocks**, one per heat-set insert, forcing
100% infill around each bore. Without them the 2.80 mm roof the minimum-wall assertion
checks is only about 2 mm of solid with ~1.1 mm of 40% gyroid in between — and heat-set
inserts want material to displace into, not voids. Raising infill globally is not the
alternative (it warps the plate) and extra walls never reach the roof above a void, so
local density is the only lever. The blocks are drawn off the same expression that cuts
the bore. **Watch for this failure mode:** `Mesher.add_shape()` on a compound of disjoint
solids silently writes only the *first*, which shipped a plate with one insert reinforced
out of three and looked correct everywhere except the slice preview. Each modifier is now
its own mesh object, and `verify()` reads the meshes back out of the zip rather than
trusting the geometry that went in.

**This was `project_settings.config` for one afternoon and it was a trap.** A project
config *replaces* the process profile: the five keys applied and the other ~275 fell back
to `fdm_process_common`, taking inner wall speed from 180 to 80 and acceleration from 4000
to 1000. The tube plate estimated **11 h instead of 7**, and time was the least of it —
seam, brim and overhang handling had reverted too, so it was a different print, not a slow
one. Nothing in the file looked wrong; the only symptom was the estimate. Layer height is
absent for a related reason: it has no per-object form, so the preset must supply it.

0.4 mm nozzle, 0.2 mm layers, both plates **rear-face-down, posts up, no supports needed**.

| Part | Walls | Top/bottom | Infill |
|---|---|---|---|
| tube_plate | 5 | 5 | 40% gyroid |
| mirror_plate | 6 | **8** | 40% gyroid |
| clip | 5 | 6 | 100% |
| push_knob, pull_knob | 4 | 5 | 100% |
| pocket_cap, shim | — | — | 100% |

ABS: 250–255 °C, bed 100–110 °C, **enclosure closed, cooling 0–20%**, 8–10 mm brim. Don't
push infill past ~40% on the plates — it adds internal stress and *increases* warping,
which is their main failure mode. The mirror plate's 8 bottom layers are not a nicety:
the pull-bolt bearing floor is only 3.45 mm (17 layers) and carries the mirror's weight,
and the landing-pad recess ceilings are bridged.

## Traps — things that look wrong but are deliberate

- **The push bolt circle does NOT scale with the mirror, and must not be "fixed".** At 8"
  the pull circle moves out to 3.000" (0.75R, optical) but the push circle follows it at
  a fixed 0.750" inboard, because that distance is set by the two knobs clearing each
  other radially (ADR-0002) and the knobs are identical in both cells. Scaling it
  proportionally *looks* more consistent and throws away the whole clearance budget for
  nothing. `verify()` reports the same 2.05 mm gap in both cells — if that number ever
  moves, this is why.
- **The 8" tube plate gets LESS brim than the 6" one, not more.** 5 mm against 8–10, and
  it is the bigger, warpier part. It is not an oversight: 237 mm of plate on a 250 mm bed
  leaves 6.5 mm a side and there is nowhere else to take it from. The plate has to reach
  the tube wall to take its screws, so it cannot shrink. **This is the 8" cell's one real
  risk and no assertion covers it** — a warped plate passes every check in the file.
- **The landing pads are #4 washers under #10 bolts.** Not a typo, and not an upsizing
  opportunity. A #10 washer's bore *is* clearance for a #10 bolt, so the push-bolt tip
  drops through it onto plastic and the pad does nothing — that was the real state of
  this design until 2026-07-29. A #6 washer leaves 0.9 mm² of contact and `verify()`
  rejects it; the #4 leaves 5.3 mm².
- **Clips are separate parts.** Integral, they leave a 142.4 mm opening for a 152.4 mm
  mirror — the mirror could never be installed. Do not "simplify" them back onto the posts.
- **The mirror plate is laterally unregistered on purpose, and the collimation range
  depends on it.** Tilt needs the plate to slide ~0.30 mm sideways: a pull bolt swings
  0.60 mm at the tube plate over the full 1.62°, against 0.17 mm of slop per side, so the
  plate does not tilt about a fixed point. Adding any pilot, boss or centring feature
  between the two plates — which reads as an obvious improvement — collapses the range,
  and **no assertion would catch it**. Spec §7 and §11 carry the numbers.
- **Bolt holes are drawn oversize, and only bolt holes are.** `BOLT_CLEAR_D` is what the
  hole must measure **once printed**; `drawn_hole()` adds `HOLE_LOSS` (0.30 mm, measured)
  on top of shrink to get there. This is the one place the nominal-dimension convention
  does not apply, and it cost a tube plate to find: drawn nominal, the pull holes printed
  at 0.19" — the bolt's own major diameter, no collimation range whatever. Do not
  "correct" a hole back to nominal, and do not add a new one with a bare `Circle(d/2)`.
- **`TILT_MAX = 3.0` is not the mechanism's range.** It is a conservative envelope for the
  tube-wall swing check. The real limit is ±1.62° as printed, computed by
  `pull_bolt_tilt()` from `PULL_HOLE_D`. The two are deliberately not wired together —
  `verify()` asserts the budget stays *inside* the envelope rather than deriving one from
  the other, so a change that opens the range up fails instead of widening the swing check
  along with it. Three checks bracket it: `>= TILT_NEEDED`, `< TILT_MAX`, and below the
  angle where the spring goes slack.
- **Captured nut pockets open FORWARD**, into the gap between the plates. A push bolt's
  reaction drives its nut rearward into solid plastic. Every steel-to-plastic interface in
  this design is in compression, because ABS creeps under sustained tension.
- **The pull bolt is reversed** relative to the push bolt: head forward, captured in the
  mirror plate; nut outside at the rear, inside the pull knob.
- **The pull knob's nut pocket is SHALLOWER than the nut** (`NUT_T - PULL_NUT_PROUD`), so
  the nut stands 0.4 mm proud. That is not a mistake to "correct" to a flush fit: it is
  what keeps steel, not ABS, bearing on the tube plate under sustained tension.
- **The fan is a stand-in, and the tube is scenery.** Neither is part of the cell. The fan
  in `fan()` was drawn here, not downloaded — GrabCAD and the like need an account, and
  putting a made-up shape behind a real part number would be worse than saying this. Trust
  its 40 × 40 × 10 envelope on a 32 mm pattern, which is standard, and nothing finer. Both
  are flagged `context` in `assembly.json` so they are drawn but **excluded from the
  camera framing** — include the 202 mm tube in the fit and the cell becomes a speck in
  every step.
- **Only the PULL knob is bored through.** Its bore is real work — tightening drives the
  bolt end into it. The push knob is blind: its shank leaves through the pocket opening
  (the plate-facing face), so a bore there would only be a hole out the back. Pressing a
  head into it is therefore one-way. Both pockets face FORWARD, and the push knob's cannot
  be flipped: a rear-facing pocket needs the body to reach 14 mm forward of the head into
  10.16 mm of standoff, so it would bury itself in the tube plate.
- **Knob flute depth is set directly, not by the cutter radius.** The cutters sit outside
  the rim. Centred on the rim, as they were at Ø30, a Ø5 cutter would cut 2.5 mm and leave
  0.9 mm of wall. The 30° phase is cosmetic at 12 flutes — depth is what protects the wall.
- **`_ring(..., orient=False)`** on the hex nuts. Pockets are cut by `at()`, a pure
  translation, so they all share one orientation; rotating a hex part to its station angle
  lands 30° out (90/210/330 are all 30 mod 60).
- **The post root chamfer is a loft, not a tapered extrude.** OCC's `extrude_taper` throws
  `Standard_TypeMismatch` on this profile above ~1 mm. It worked silently at 1.0 mm.
- **Tube plate OD is drawn at nominal 7.500"** with no shrinkage compensation — confirmed
  by a real test fit. Do not pre-compensate any tube-referenced dimension.
- **Mirror plate has its own `MP_CENTER_BORE`.** The tube plate's bore is set by the 40 mm
  fan screw circle; the two constraints are unrelated and must stay decoupled.

## Open items / candidate tweaks

Reviewed 2026-07-29. What is left that actually gates a print is the coupon work above —
everything in the first group below resolves with the coupon in hand plus one bolt.

**Blocking:**

- **`FIT_SLIP`** — predicted, not measured. Blocks the mirror plate only. Row H, one
  10-24 hex bolt.
- **The press fit in a 2.2 mm knob wall** — see above. Blocks the knobs only.
- **`coupon_insert` has not been sectioned.** The bores themselves passed (2026-07-29, see
  above), but nothing has confirmed the `insert_solid` modifier produced solid material
  around the bore in the plastic rather than only in the file. Snap one bore open and look.
  Worth doing *before* the tube plate goes on the bed — that print is 5½–7 h.

**Closed or downgraded:**

- ~~Fan~~ — future-proofing, not vital. Holes exist, envelope is checked, nothing is
  bought. The solid in the viewer remains a stand-in — see the traps.
- ~~Tube-mount screw length~~ — ½", or ⅝" once the fender washer is on. Hole positions
  evaluated; confirmed at assembly rather than modelled.
- ~~Springs~~ — bought. 1.0 mm wire × 9 mm OD × 20 mm 304 stainless, the substitute
  recorded in spec §7: ≈18 lb/in against the specified 13, so ≈1.4× preload and knobs
  that turn ~40% stiffer. Error runs the safe way. Confirm the feel on first assembly.
- ~~Knob geometry~~ — 2.5 cc and ~15 min each, so iterating is cheap. A fitting session,
  not a design unknown. Outlines are still unstyled if you want them prettier.
- ~~Seating checks for bolt heads and clips~~ — **added, and both were verified by
  breaking the model.** See the method note.
- ~~Mirror plate thickness~~ — resolved at 0.375", and now commented at the constant with
  the reason. It is pinned by **bolt length, not stiffness**: the pull-bolt head is
  captured in this plate with its nut outside, so thickness comes straight off the thread
  the nut runs on. At 0.500" with the same 1½" bolts the thread runs out **+0.23 mm**
  past nominal instead of +3.41 mm — one collimation and no second chance. 1⅝" pull bolts
  restore it but break the one-length rule; 1¾" overshoots and the spring goes slack
  first. All three were run. Do not thicken it without re-opening ADR-0002.

**Open on the 8" cell specifically:**

- **Nothing has been printed.** The measured fits carry over (identical hardware), so the
  coupon work is not repeated — but the tube plate's warp behaviour at 237 mm is unknown
  and is the thing to find out first. Print that plate before buying anything else.
- **The 25 mm spring has not been sourced.** ~12 lb/in at 1.0 mm wire × 9 mm OD × 25 mm
  free length. Same caveat as the 6" cell's: no vendor at this price states an active coil
  count, so the rate is inferred and `SPRING_SOLID_H = 8.0` is an estimate checked only
  against the plate gap, where it has 4 mm of margin.
- **The mirror plate's centre bore is still 56 mm**, which was sized for the 6" cell and
  is now proportionally small for a mirror needing more cooling. Opening it is free
  airflow — `verify()` allows up to ~100 mm before it reaches the landing-pad recesses.

**Still open, non-blocking:**

- **Bolt and spring solids in the viewer are still procedural.** The heads are now checked
  against their pockets by `verify()`, but what the *viewer* draws is unmatched. A vendor
  solid would close the cosmetic gap.
- **Spring rate is still inferred, not published.** No vendor at this price states active
  coil count; across a plausible 4.5–6 coil spread the bought spring lands 16–21 lb/in.
  Resolves by feel on first assembly.

## Method note

Assertions in `verify()` encode the spec, and several of them were **verified by
reintroducing the bug on purpose** — that is worth continuing. In this project three
checks initially passed a broken model because the *check* was wrong, so a new assertion
is not trustworthy until it has been seen to fail.

**2026-07-29 — a fourth check joined that list, and the cause is worth knowing.** The new
bolt-head test was written above `solid(nm)`, and `verify()` also bound `solid` as a float
(`free, solid = 20.0, 6.2`) further up. The check therefore intersected against a float,
threw, and a blanket `except Exception: clash = 0.0` reported **PASS on four separately
broken models**. The float is now `solid_h`, the check sits below `solid(nm)`, and its
intersection is deliberately *not* wrapped — an exception there should be a crash, not a
green tick. The other seating checks still carry that `except`; it is load-bearing for
genuinely disjoint solids, but it is the reason this bug was invisible.

**A check must be asked where it can also be answered.** The BOM snapshot check lived in
`verify()`, which raises `SystemExit` before the write — so editing any BOM note failed the
run that would have fixed it, and every rerun failed identically. It is now a query
(`bom_snapshot_stale()`) asked *after* the write: the default run repairs the file and says
which rows moved, and `--check` refuses a stale one and writes nothing. Same guarantee,
minus the deadlock.

The strongest checks are the ones that test **solids against solids** (does this part fit
in that recess; is the mirror's volume clear) rather than comparing numbers that were
typed in. Prefer those.

**2026-07-29 — the clearest demonstration yet of why.** `insert_coupon()` aimed both
radial bore cuts *outward* from the rim. They removed nothing, and the coupon shipped with
no 10-24 bores at all — its only holes were the two vertical M3 ones. All five insert
checks passed, because all five were arithmetic on constants: roof depth, bore spacing,
bore depth against the block. Every one of those numbers was correct. Nothing asked the
solid whether the hole was there. It is now asked directly — each intended bore is
intersected with the coupon and must come back empty, and must break the rim face — and
both were confirmed by restoring the old direction and watching four checks fail. If the
coupon had been printed first, the print would have looked fine and taught nothing.

Two smaller things fell out of the same fix:

- `write_3mf()` named modifier `<part>` entries by iterating `STATIONS`, so it emitted
  three however many modifier solids it was handed. A caller with two got a dangling
  `<part id="4">`. Numbering now comes off the modifier list itself.
- The coupon's modifier blocks are 12.3 mm wide and were about to merge across a 24 mm
  block, which would have printed the whole coupon solid — reproducing the dense region
  but not the 40 % field it sits in, and making the "coupon exercises sparse infill"
  assertion a fiction. `IC_Y` is derived from the block width now, not typed.

**The fit coupon was then audited for the same weakness and had it, without the bug.**
All nineteen of its features are genuinely cut — probed and confirmed — but only three of
its fourteen checks touched the solid, and none asked whether any feature existed. A plain
slab would have passed everything except the two bounding-box checks, which only see the
outline. The head row had no solid check at all, which is the row that decides `FIT_SLIP`
— still the one predicted rather than measured. `test_coupon.py` is now 103 checks.

Two things in that fix are worth copying elsewhere:

- **A probe placed from the same table that cuts the feature cannot, alone, prove the
  feature is real.** A table entry describing a hole outside the plate moves the cut and
  the probe together: the cut removes nothing, the probe finds nothing, both agree, and
  the check passes. Each feature is therefore required to lie in the *uncut blank* first,
  and to be gone from the finished part second. Only the pair means anything. All four
  failure modes — sunk below the plate, off the edge, never cut, and hardware too big for
  its pocket — were reintroduced and watched to fail.
- `hex_head()` is now a function in `mirror_cell.py` beside `hex_nut()`. It is not a
  printed part and not in `PARTS`; it exists so checks can put real hardware into a real
  recess. It was an expression written out inside `verify()`, and the coupon needed the
  same one.

The blanket `except Exception: clash = 0.0` around the coupon's nut seating check is gone.
It was not inert — the intersection ran — but it is the construct that reported PASS on
four broken models here, and there is no reason to keep it.

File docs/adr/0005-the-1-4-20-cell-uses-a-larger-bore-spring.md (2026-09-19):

# The 1/4-20 cell uses a larger-bore spring

The spring rides on the pull bolt's shank. The 9 mm springs both cells were designed
around have a **7.0–7.2 mm** coil bore (OD − 2·wire), which clears the 10-24 shank
(4.83 mm) by about **1.1 mm per side**. A 1/4-20 shank is **6.35 mm**, which the same
spring clears by only **0.33–0.43 mm per side** — it slides on, but the margin is gone.

That matters because the pull bolt **leans**. It is the one that tilts for collimation, and
at full range it moves the shank sideways across the spring's 16.24 mm span by
`span·tan(tilt)` ≈ **0.55 mm**. At 10-24 that is well inside the 1.1 mm of clearance. At
1/4-20 it is larger than the 0.33 mm/side the 8" spring had, so the spring would bear on
the bolt where it previously cleared it — rubbing, and a lateral load the spring was never
sized for.

## The fix

Same wire, larger **OD — 9 → 10.5 mm**, which takes the coil bore to **8.5–8.7 mm** and the
clearance back to **~1.1 mm/side**, matching the 10-24 cell. A larger OD makes the spring
softer (`k ∝ 1/D³`, so ~40 % less), and the preload is bought back with **free length**,
exactly as ADR-0003 did for the 8" cell:

| | wire | OD | free length | bore | clearance/side | preload/station |
|---|---|---|---|---|---|---|
| 6", 10-24 | 0.9 mm | 9 mm | 20 mm | 7.2 mm | 1.19 mm | 1.92 lb |
| 6", 1/4-20 | 0.9 mm | 10.5 mm | **23 mm** | 8.7 mm | 1.17 mm | 2.08 lb |
| 8", 10-24 | 1.0 mm | 9 mm | 25 mm | 7.0 mm | 1.09 mm | 4.14 lb |
| 8", 1/4-20 | 1.0 mm | 10.5 mm | **31 mm** | 8.5 mm | 1.08 mm | 4.18 lb |

The free lengths are what hold the preload: at the cell's 16.24 mm of seat + gap, the
longer spring is compressed further and makes up for the softer rate. Both 1/4-20 springs
land at roughly **2× the moving assembly**, the same place the 10-24 ones do, and the
preload check in `verify()` computes it from geometry rather than trusting the table.

The springs are a per-bolt override in the `BOLTS` entry (`spring={6: …, 8: …}`), not in
`CELLS`: the cell's own spring is the 10-24 one, and a larger bolt replaces it.

## Consequences

- **The spring assertion now means something.** It used to say only that the bore was
  0.2 mm larger than the bolt — true of the too-tight 9 mm spring as well. It now requires
  the per-side clearance to exceed the shank's sway at full tilt (`span·tan(pull_bolt_tilt())`),
  which is the number that was actually at risk. It passes at ~1.1 mm/side against 0.46 mm
  of sway (10-24) and 0.55 mm (1/4-20).
- **The bill of materials has four possible springs**, one per aperture × bolt size. The
  two 1/4-20 ones are a separate purchase; the rate and solid height are inferred from the
  geometry, as they are for the originals, because no vendor at this price states a coil
  count (see HANDOFF).
- **The tube plate's spring seat opens** from Ø9.8 to Ø11.3 mm (`SPRING_SEAT_D`), so the
  1/4-20 tube plate is a different part from the 10-24 one. The 10-24 geometry is
  untouched and bit-identical.
- **Reversible**: select 10-24 and the 9 mm springs come back.

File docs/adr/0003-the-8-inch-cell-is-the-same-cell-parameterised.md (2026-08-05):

# The 8″ cell is the same cell, parameterised — not a second design

An 8.000″ × 1.330″ mirror in a 10.000″ ID tube is now built from `mirror_cell.py` by
`--aperture 8`. It is the **same cell**: the same three stations, the same push/pull
mechanism, the same landing pads, captured nuts, heat-set inserts, knobs, clips, pocket
caps and shims. Three numbers change in `CELLS` — mirror diameter, mirror thickness, tube
ID — and everything geometric follows from them. One purchased item changes with the
load, and one manufacturing constraint bites.

The alternative was a branch or a copied file per aperture. Both were rejected for the
same reason: this model's value is in its **171 assertions**, several of which were only
trusted after being watched to fail (see HANDOFF's method note). A fork duplicates the
assertions and then lets the two copies drift, so a check repaired on one cell silently
stays broken on the other. One file with a config table keeps the 6″ cell — the one that
has actually been printed and measured — as a permanently verified control.

## What scales, and what deliberately does not

| | Rule | 6″ | 8″ |
|---|---|---|---|
| Pull-bolt / support circle | `0.375 × MIRROR_D` (0.75R, ADR-0001) | 2.250″ | 3.000″ |
| Push-bolt circle | `R_PULL − 0.750″` | 1.500″ | 2.250″ |
| Tube plate rim | `TUBE_ID / 2` | 95.25 | 127.0 |
| Tube plate flat | 6″ cell's proportion of the rim | 60.0 | 80.0 |
| Mirror plate rim | `POST_IR + POST_T + 3.04` | 88.0 | 113.4 |
| Post height | `RTV_T + MIRROR_T + CLIP_GAP` | 28.1 | 36.1 |

**The push circle does not scale, and that is the point.** Its distance inboard of the
pull circle is set by the two knobs clearing each other radially (ADR-0002), and the knobs
are identical in both cells because the hardware inside them is. Holding the 0.750″ budget
reproduces the 2.05 mm gap exactly at 8″; scaling it proportionally would have thrown away
19 mm of clearance to buy nothing.

**All the hardware is unchanged**: 10-24 throughout, six 1½″ machine screws, six hex nuts,
#4 landing washers, ruthex RX-10-24×9.5 inserts, M3 post inserts, the 40 mm fan pattern,
and the measured `FIT_PRESS` / `FIT_SLIP` / `HOLE_LOSS` numbers. So does `TUBE_PLATE_T`,
which means the insert roof stays at 2.80 mm and the collimation range stays at ±1.62°
— it is set by the bolt hole and the plate thickness, neither of which moved.

## Why 0.75R still holds

ADR-0001 records a tripwire: *"This reasoning does not transfer. It holds only because the
blank is full-thickness and small."* That tripwire is respected rather than ignored, and
the reason it does not fire here is the **thickness the user specified**.

Both blanks are 6:1 — 6.000/1.000 and 8.000/1.330. At constant diameter-to-thickness
ratio, self-weight deflection of a plate goes as `R⁴/t³`, i.e. **linearly in R**, so the
8″ blank deflects about **1.33×** the 6″ one. Against `~/blip`'s finding that the whole
span from 0.40R to the extreme edge is under 1/40 wave at 6″, that is roughly 1/30 wave at
8″ — still optically indifferent, so the load-path argument still decides and the support
points still belong over the pull bolts.

**This is where the file stops.** 8″ is at the edge of the 3-point validity range, and a
thinner 8″ blank (a 1″ plate glass disc, say, at 8:1) is *not* covered by the arithmetic
above — it deflects 2.4× the 6″ cell, and support placement starts to matter again. A
third `CELLS` entry is not a licence; it needs its own version of this paragraph.

## The spring is the one purchased item that changes

8″ × 1.33″ glass is **2574 g against 1089 g**, and the moving assembly goes from 2.68 lb
to 6.11 lb. The 6″ cell's spring makes 1.92 lb per station and **fails the preload check
outright** here — 5.77 lb of spring against a requirement of 9.2. That failure is correct
and was the first thing the new configuration reported.

The force is bought with **free length, not rate**: the seat and the plate gap consume a
fixed 16.24 mm of any spring fitted, so a longer spring arrives further compressed. At
25 mm free length the compression goes 3.76 → 8.76 mm, and a spring *no stiffer than the
6″ cell's* (12 lb/in against 13) makes **4.14 lb per station, 12.4 lb total, 2.03×** the
moving assembly — the same margin the 6″ cell carries.

Buying it as rate instead would have meant ~27.5 lb/in in the 20 mm envelope, roughly
double the torque at the knob. HANDOFF already names grip as this design's weakest point:
a Ø18 fluted ABS knob turned with cold fingers in the dark. Doubling what it takes to turn
it, to avoid changing a part number, would have been the wrong trade.

The longer spring also *widens* a margin that was tight at 6″: the thread runs out
3.41 mm before the spring goes slack there with only 0.35 mm to spare, and 5.35 mm to
spare at 8″.

## Consequences

- **The bed is now the binding constraint, and it is close.** The tube plate must reach
  the tube wall to take its screws, so a 10″ tube puts a **237 × 207 mm** part on a
  250 × 250 mm bed. The 8–10 mm ABS brim the 6″ cell prints with does not fit; the
  8″ cell is specified at **5 mm**, leaving 6.5 mm of bed. `BRIM` is therefore part of
  the bed-fit assertion rather than a slicer note, so any part that grows fails a check
  instead of failing on the bed.
- **Warp risk goes up and is not modelled.** A 237 mm ABS plate at 40% gyroid is a
  materially harder print than the 178 mm one, and it gets *less* brim, not more. Nothing
  in `verify()` can catch this — it is the one place where the 8″ cell is riskier in a way
  no assertion covers. Print it first, before anything else in the cell.
- **Outputs are separated.** `build/` and `BOM.md` for the 6″, `build-8/` and `BOM-8.md`
  for the 8″, so neither cell can overwrite the other's exports or snapshot. The viewer
  takes `?cell=8`.
- **The coupons are shared and stay in `build/`.** They test hardware fits — hex pockets,
  insert bores — and that hardware is identical in both cells, so `FIT_PRESS = 0.10` and
  the passed insert coupon carry over unchanged. This is the main thing the 8″ cell
  inherits for free.
- **Nothing about the 8″ cell has been printed**, including the tube plate that is the
  reason for the bed caveat above.

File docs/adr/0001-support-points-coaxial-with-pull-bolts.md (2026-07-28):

# Support points are coaxial with the pull bolts at 0.75R, not at the PLOP optimum

PLOP-style optimisation puts the three support points of a 3-point cell near **0.40R**,
and the classical Grubb/Stellafane result puts them at **0.707R**; we have placed them at
**0.75R**, directly over the pull bolts, and chose that on mechanical rather than optical
grounds. The justification is `~/blip`, our own FEA of this exact mirror, which found that
for a full-thickness 6" blank the difference between these placements is **under 1/40 wave
— supporting at the extreme edge is still only 1/30 wave**, i.e. optically undetectable at
the eyepiece. With optics thus indifferent, the load path decides: putting the support
points on the same ray *and the same radius* as the pull bolts means the mirror's weight
travels mirror → silicone dab → boss → bolt → tube plate with **no bending moment in the
mirror plate at all**, which matters enormously for a printed ABS part, where bending is
the weak direction and the place creep shows up.

## Consequences

- The mirror plate can be a light three-armed triangle instead of a stiff disk — less
  plastic, shorter print, better airflow behind the mirror for cooldown.
- 0.75R is close enough to the classical 0.707R that the cell will not look strange to
  another ATM.
- **This reasoning does not transfer.** It holds only because the blank is full-thickness
  and small. For a thin or larger mirror the deflection is no longer negligible, support
  placement matters again, and this cell should not be reused as a starting point — that
  is recorded as a tripwire in the spec.
- The decision is effectively irreversible: moving the support points means unglueing a
  mirror bonded with RTV.

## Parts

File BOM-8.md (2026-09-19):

# Bill of materials — 8" mirror cell

Generated by `mirror_cell.py --aperture 8`, which writes it to
`build-8/` and commits this copy as `BOM-8.md`. Every number comes from the
model — quantities are counted off the assembly, dimensions read from the
parameters — so **regenerate this file rather than editing it**. `--check` fails
if the committed copy has gone stale.

For a 8" × 1.33" mirror in a 10" ID tube.

**17 printed pieces** from 7 distinct parts, plus the buy list below.

Printer settings that apply to everything: 0.4 mm nozzle, 0.2 mm layers, ABS at
250–255 °C, bed 100–110 °C, **enclosure closed, part cooling 0–20 %**, 5 mm brim.
Both plates print rear-face-down with no supports.

## Printed parts

| Qty | Part | Slicer | Why it is like that |
|---:|---|---|---|
| 1 | `tube_plate` | 5 walls / 5 solid / 40% gyroid, 378.66 cc each | Rear face down, no supports. Do not raise the infill: it adds internal stress and INCREASES warping, which is this plate's main failure mode. |
| 1 | `mirror_plate` | 6 walls / 8 solid / 40% gyroid, 275.31 cc each | Rear face down, posts up, no supports. The 8 bottom layers are not a nicety -- the pull-bolt bearing floor is only 3.45 mm and carries the mirror, and the landing-pad recess ceilings are bridged. |
| 3 | `clip` | 5 walls / 6 solid / 100%, 2.35 cc each | Prints flat, which puts the 0.030" air-gap face on the bed as a clean surface instead of a supported overhang. Separate from the posts on purpose: printed integrally they leave a 193.2 mm opening for a 203.2 mm mirror. |
| 3 | `push_knob` | 4 walls / 5 solid / 100%, 2.07 cc each | Blind hex pocket for a bolt HEAD. Pressing a head in is one-way -- there is no bore behind it to push against. |
| 3 | `pull_knob` | 4 walls / 5 solid / 100%, 2.47 cc each | Hex pocket for a NUT, deliberately shallower than the nut. PRINT ONE FIRST and press a nut in: the pocket sits in a 2.2 mm wall, and the 0.10 mm fit was measured in a 6 mm plate. |
| 3 | `pocket_cap` | 100% infill, 0.16 cc each | A loose fit on purpose -- bedded in a spot of RTV, so there is no press fit to dial in. |
| 3 | `shim` | 100% infill, 0.57 cc each | Assembly aid only. Sets the 0.0625" bond, then comes out at step 8. |

## Purchased

| Qty | Item | Spec | Why |
|---:|---|---|---|
| 6 | 10-24 hex-head MACHINE screw | 1.5" long (38.1 mm), zinc or stainless | Machine screws, NOT hex cap screws: a 10-24 cap screw carries an unthreaded shank where the captured nut in the tube plate needs thread. One length for all six, and a 1/2" multiple, because odd lengths are a nuisance to source. |
| 6 | 10-24 hex nut | 0.375" across flats, 0.13" thick | Three press into the tube plate's forward face (captured, for the push bolts), three press into the pull knobs. Identical parts -- the pull knob is what replaced the wing nut. |
| 3 | #4 flat washer (landing pad) | 0.3125" OD, 0.125" bore, 0.032" thick | A #4 washer under a 10-24 bolt, and that is NOT a typo. What the push-bolt tips bear on -- steel on steel, so no bolt ever embosses the plastic and walks the collimation. The bore has to be SMALLER than the bolt's point or the pad does nothing: a washer sized for the bolt has a free-fit clearance bore, so the tip drops through it and lands on plastic. The 0.125" bore here is what the point rests on. |
| 3 | Compression spring | 1 mm wire x 9 mm OD x 25 mm free length (~12 lb/in) | BUY BY GEOMETRY, NOT BY RATE -- rate follows k = Gd^4/8D^3n and wire diameter dominates at the fourth power. Do not buy a 'telescope collimation spring kit': those compute to ~152 lb/in, more than ten times this, and you would never turn the pull knobs. Gives 4.14 lb per station at the 0.6" gap. The FREE LENGTH is what carries the load here: the seat and the gap eat a fixed 16.24 mm of any spring fitted, so a shorter one of the same rate arrives with less preload, not the same preload. |
| 3 | 10-24 heat-set insert | 6.5 mm bore x 14 mm | ALWAYS 10-24, whichever collimation bolts are selected -- a 1/4-20 insert does not fit the 0.500" tube plate (ADR-0004). Radial, in the tube plate rim, at mid-thickness. These three screws carry the entire cell -- mirror, plates and hardware. Dimensioned around [ruthex RX-10-24x9.5](https://www.ruthex.de/en/products/ruthex-10-24-gewindeeinsatz-zoll-unc-50-stuck-rx-10-24x9-5-gewindebuchsen-aus-messing-stabile-einpressmutter-durch-warme-in-3d-druc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) -- 7.1 mm OD, 9.5 mm long, 6.4 mm recommended hole. The 6.5 mm bore drawn here prints at ~6.45 mm at the measured 0.8% shrink, so do NOT compensate it. Roof over the seated insert is 2.80 mm against ruthex's 2.6 mm minimum wall -- the tight dimension, and why the insert coupon is worth reading before this plate goes on the bed. |
| 3 | #10 screw (tube mount) | length to suit: tube wall 0.125" + washer + insert reach | Goes through the sonotube into the inserts above. Drill the tube using the insert bores as the guide, at the depth that reaches focus. |
| 3 | 1" fender washer | 1" OD, #10 bore | OUTSIDE the tube, and not optional. Statically the screws see ~70 psi against cardboard good for 1000, but a 10 g transport knock puts ~700 psi on the hole edge: the holes go oval and collimation is gone every time you move the scope. A fender washer spreads it ~15x. |
| 3 | M3 heat-set insert | 4 mm bore x 6 mm | Into the tops of the centering posts, for the clips. |
| 3 | M3 cap screw | ~10 mm | Holds a clip. Never snug one down onto the glass -- the clips are drop-insurance standing 0.030" clear, not a clamp. |
| 1 | Black ABS filament | 677 cc of part volume (0.70 kg of ABS) -- a 1 kg spool covers it with the brim and a reprint | ABS for the heat: a black cell in a closed tube sits in the sun. It also creeps under sustained tension, which is why every steel-to-plastic interface in this design is loaded in compression. |
| 1 | RTV silicone | neutral-cure, small tube | Three dabs under the mirror at 0.0625", plus a spot under each pocket cap. NOT acetic-cure (the vinegar smell) near an aluminised surface. |

---

Traps worth re-reading before you buy: machine screws (not cap screws),
springs by geometry (not by rate), and fender washers on the OUTSIDE of the
tube. See `mirror-cell-spec.md` §7 and `HANDOFF.md`.

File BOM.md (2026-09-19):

# Bill of materials — 6" mirror cell

Generated by `mirror_cell.py --aperture 6`, which writes it to
`build/` and commits this copy as `BOM.md`. Every number comes from the
model — quantities are counted off the assembly, dimensions read from the
parameters — so **regenerate this file rather than editing it**. `--check` fails
if the committed copy has gone stale.

For a 6" × 1" mirror in a 7.5" ID tube.

**17 printed pieces** from 7 distinct parts, plus the buy list below.

Printer settings that apply to everything: 0.4 mm nozzle, 0.2 mm layers, ABS at
250–255 °C, bed 100–110 °C, **enclosure closed, part cooling 0–20 %**, 10 mm brim.
Both plates print rear-face-down with no supports.

## Printed parts

| Qty | Part | Slicer | Why it is like that |
|---:|---|---|---|
| 1 | `tube_plate` | 5 walls / 5 solid / 40% gyroid, 204.69 cc each | Rear face down, no supports. Do not raise the infill: it adds internal stress and INCREASES warping, which is this plate's main failure mode. |
| 1 | `mirror_plate` | 6 walls / 8 solid / 40% gyroid, 166.38 cc each | Rear face down, posts up, no supports. The 8 bottom layers are not a nicety -- the pull-bolt bearing floor is only 3.45 mm and carries the mirror, and the landing-pad recess ceilings are bridged. |
| 3 | `clip` | 5 walls / 6 solid / 100%, 1.76 cc each | Prints flat, which puts the 0.030" air-gap face on the bed as a clean surface instead of a supported overhang. Separate from the posts on purpose: printed integrally they leave a 142.4 mm opening for a 152.4 mm mirror. |
| 3 | `push_knob` | 4 walls / 5 solid / 100%, 2.07 cc each | Blind hex pocket for a bolt HEAD. Pressing a head in is one-way -- there is no bore behind it to push against. |
| 3 | `pull_knob` | 4 walls / 5 solid / 100%, 2.47 cc each | Hex pocket for a NUT, deliberately shallower than the nut. PRINT ONE FIRST and press a nut in: the pocket sits in a 2.2 mm wall, and the 0.10 mm fit was measured in a 6 mm plate. |
| 3 | `pocket_cap` | 100% infill, 0.16 cc each | A loose fit on purpose -- bedded in a spot of RTV, so there is no press fit to dial in. |
| 3 | `shim` | 100% infill, 0.57 cc each | Assembly aid only. Sets the 0.0625" bond, then comes out at step 8. |

## Purchased

| Qty | Item | Spec | Why |
|---:|---|---|---|
| 6 | 10-24 hex-head MACHINE screw | 1.5" long (38.1 mm), zinc or stainless | Machine screws, NOT hex cap screws: a 10-24 cap screw carries an unthreaded shank where the captured nut in the tube plate needs thread. One length for all six, and a 1/2" multiple, because odd lengths are a nuisance to source. |
| 6 | 10-24 hex nut | 0.375" across flats, 0.13" thick | Three press into the tube plate's forward face (captured, for the push bolts), three press into the pull knobs. Identical parts -- the pull knob is what replaced the wing nut. |
| 3 | #4 flat washer (landing pad) | 0.3125" OD, 0.125" bore, 0.032" thick | A #4 washer under a 10-24 bolt, and that is NOT a typo. What the push-bolt tips bear on -- steel on steel, so no bolt ever embosses the plastic and walks the collimation. The bore has to be SMALLER than the bolt's point or the pad does nothing: a washer sized for the bolt has a free-fit clearance bore, so the tip drops through it and lands on plastic. The 0.125" bore here is what the point rests on. |
| 3 | Compression spring | 0.9 mm wire x 9 mm OD x 20 mm free length (~13 lb/in) | BUY BY GEOMETRY, NOT BY RATE -- rate follows k = Gd^4/8D^3n and wire diameter dominates at the fourth power. Do not buy a 'telescope collimation spring kit': those compute to ~152 lb/in, more than ten times this, and you would never turn the pull knobs. Gives 1.92 lb per station at the 0.6" gap. The FREE LENGTH is what carries the load here: the seat and the gap eat a fixed 16.24 mm of any spring fitted, so a shorter one of the same rate arrives with less preload, not the same preload. |
| 3 | 10-24 heat-set insert | 6.5 mm bore x 14 mm | ALWAYS 10-24, whichever collimation bolts are selected -- a 1/4-20 insert does not fit the 0.500" tube plate (ADR-0004). Radial, in the tube plate rim, at mid-thickness. These three screws carry the entire cell -- mirror, plates and hardware. Dimensioned around [ruthex RX-10-24x9.5](https://www.ruthex.de/en/products/ruthex-10-24-gewindeeinsatz-zoll-unc-50-stuck-rx-10-24x9-5-gewindebuchsen-aus-messing-stabile-einpressmutter-durch-warme-in-3d-druc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) -- 7.1 mm OD, 9.5 mm long, 6.4 mm recommended hole. The 6.5 mm bore drawn here prints at ~6.45 mm at the measured 0.8% shrink, so do NOT compensate it. Roof over the seated insert is 2.80 mm against ruthex's 2.6 mm minimum wall -- the tight dimension, and why the insert coupon is worth reading before this plate goes on the bed. |
| 3 | #10 screw (tube mount) | length to suit: tube wall 0.125" + washer + insert reach | Goes through the sonotube into the inserts above. Drill the tube using the insert bores as the guide, at the depth that reaches focus. |
| 3 | 1" fender washer | 1" OD, #10 bore | OUTSIDE the tube, and not optional. Statically the screws see ~70 psi against cardboard good for 1000, but a 10 g transport knock puts ~700 psi on the hole edge: the holes go oval and collimation is gone every time you move the scope. A fender washer spreads it ~15x. |
| 3 | M3 heat-set insert | 4 mm bore x 6 mm | Into the tops of the centering posts, for the clips. |
| 3 | M3 cap screw | ~10 mm | Holds a clip. Never snug one down onto the glass -- the clips are drop-insurance standing 0.030" clear, not a clamp. |
| 1 | Black ABS filament | 392 cc of part volume (0.41 kg of ABS) -- a 1 kg spool covers it with the brim and a reprint | ABS for the heat: a black cell in a closed tube sits in the sun. It also creeps under sustained tension, which is why every steel-to-plastic interface in this design is loaded in compression. |
| 1 | RTV silicone | neutral-cure, small tube | Three dabs under the mirror at 0.0625", plus a spot under each pocket cap. NOT acetic-cure (the vinegar smell) near an aluminised surface. |

---

Traps worth re-reading before you buy: machine screws (not cap screws),
springs by geometry (not by rate), and fender washers on the OUTSIDE of the
tube. See `mirror-cell-spec.md` §7 and `HANDOFF.md`.

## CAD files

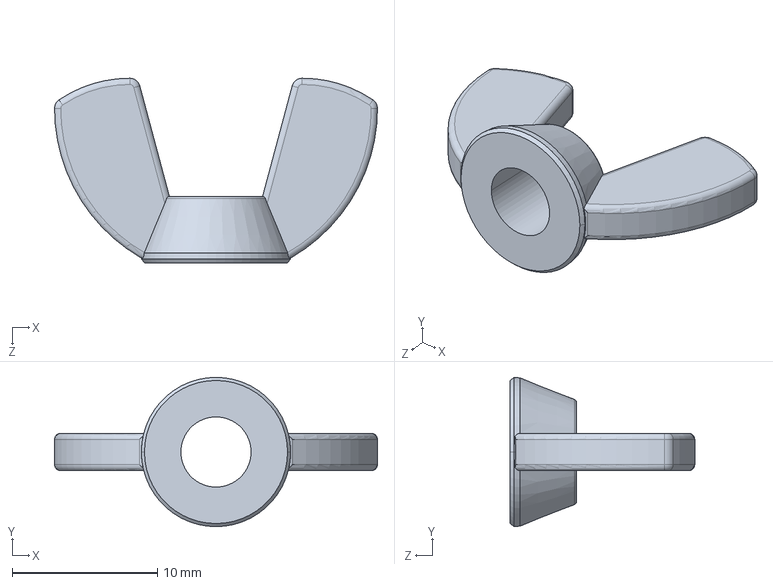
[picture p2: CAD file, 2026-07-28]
90866A011_NO THREADS_Zinc-Plated Steel Wing Nut.STEP
22.2 x 10.3 x 12.7 mm

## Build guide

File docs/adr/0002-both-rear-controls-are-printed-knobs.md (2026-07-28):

# Both rear controls are printed knobs, clearing each other radially

The Push knob and the Pull knob sit on the same Station ray, 19.05 mm apart, and something
has to give. The cell previously gave axially: a Ø30 printed knob on the push bolt overlaps
a 0.875″ wing nut on the pull bolt by **7.06 mm radially**, so the push bolts were
lengthened to 2″ purely to drop the knob 10.16 mm below the wing nut. Both rear controls
are now **printed knobs** — Ø16 on the push station, Ø18 on the pull, the latter capturing
a plain 10-24 hex nut in place of the wing nut — sized so they clear each other **radially,
by 2.05 mm**.

The argument is not that a printed knob is nicer than a wing nut. It is that **radial
clearance is unconditional and axial clearance is not.** The axial escape depended on the
push bolt's length *and on where the adjusters happened to be set*: advancing the push
screw carries its knob back toward the plate and into the wing nut's z-band. Nothing in the
model checked the second dependency, because with a knob 22.9 mm behind the plate it never
bound. A radial clearance between two circular knobs on fixed bolt circles cannot be
violated by any adjustment, any bolt length, or any assembly error.

Buying the clearance radially requires controlling *both* parts, which is why the wing nut
has to go rather than merely shrink. A ½″ knurled thumb screw on the push station would
also have cleared it (1.46 mm after shrink), and remains a valid alternate — but it leaves
the pull side dictating the push bolt's length, and it makes the build depend on a
specialty fastener.

## Consequences

- **All six bolts become 10-24 × 1½″**, one type and one length, and a ½″ multiple, which
  is what is actually stocked. `verify()` asserts both properties so they cannot rot. Buy
  **machine screws**: a #10 hex *cap* screw carries an unthreaded shank about 19 mm long,
  exactly where the captured nut needs thread.
- **One nut type, six of them.** Three captured in the tube plate, three in the pull knobs.
  The wing nut leaves the bill of materials.
- **Rear stack-out falls from 36.9 mm to 24.2 mm.**
- **The pull knob joins the load path.** Its nut stands `PULL_NUT_PROUD` = 0.4 mm out of
  the knob's face, so steel bears on the tube plate exactly as the wing nut's steel did and
  the printed body never touches it. An ABS face rotating on an ABS face under sustained
  tension is the one loading this design refuses everywhere (spec §6): ABS creeps.
- **Grip is the thing given up.** A Ø18 fluted ABS knob is worse with cold fingers than a
  0.875″ steel wing nut, and the pull knob is the control you turn in the dark. That is the
  price of the radial solution, paid knowingly. Height is the cheap dimension now — nothing
  lives behind the knobs — so if grip disappoints, make them taller before wider.
- **The diameters are not free choices.** The 19.05 mm budget splits so the two walls come
  out equal: the pull knob captures a nut (11.11 mm across corners), the push knob only a
  head (9.28), so the pull knob takes the larger share. Flute depth, not flute phase, is
  what protects the wall at 12 flutes.
- **The wing nut's vendor solid stays in the repo** as the evidence for the 7.06 mm figure
  above. It measured 22.225 × 12.700 mm; the catalogue-derived estimates it replaced (19.0
  × 11.0) were both undersized, which is why the number is worth keeping checkable. Nothing
  imports it any more.
- **This is reversible**, unlike ADR-0001. Both knobs are ~2 cc prints. Going back to a
  wing nut means 2″ push bolts and a push knob no larger than Ø15.7.

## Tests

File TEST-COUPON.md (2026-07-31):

# Test coupon — printing and reading it

This print is the only thing standing between the model and a real cell. `FIT` (hex
pocket clearance) is a 0.25 mm placeholder, and no assertion can check it: ABS shrinks
0.6–0.8 %, how much of that reaches a small internal pocket depends on the slicer
profile rather than the geometry, and a pocket that is 0.15 mm tight cracks a plate you
spent three and a half hours printing.

```sh
python3 test_coupon.py     # 101 checks, then build/coupon_fit.* and build/coupon_insert.*
```

It also writes `build/coupons.json`, which puts both coupons in the viewer's
**Download STEP** list alongside the cell parts.

Geometry is in [test_coupon.py](./test_coupon.py). Every pocket is cut by `mirror_cell`'s
own `hex_prism()` at `mirror_cell`'s own depths, so the coupon cannot drift away from the
parts it stands in for.

## What is on it

**`coupon_fit`** — 100.000 × 50.000 × 6 mm plate, ~25 cc.

| Feature | Where | What it decides |
|---|---|---|
| Six 10-24 **nut** pockets, row `N` | top face, fits 0.10 → 0.40 | `FIT` for the captured push-bolt nut (tube plate) |
| Six 10-24 **head** pockets, row `H` | top face, same ladder | `FIT` for the captured pull-bolt head (mirror plate) *and* the push knob |
| Ø12.0 × 1.5 counterbore | bottom left | printed cap disc into printed bore |
| Two Ø8.24 / Ø8.54 pad recesses | **bed face** | the #4 washer landing pad |
| Ø9.8 × 2.5 seat | bottom right | the spring drops in and does not bind |
| Ø5.50 through hole | far right | the **pull** hole: prints at Ø5.16, the collimation range |
| Ø5.95 through hole | far right | the **pass-through** hole: prints at Ø5.60 |
| The outline itself | — | **shrink gauge**: drawn at exactly 100.000 × 50.000 |

The engraved number above each column is the clearance added to across-flats. The notched
corner marks the tight (0.10) end. Every hex pocket has a through hole so a fastener that
turns out to be a press fit can be punched back out.

**`coupon_insert`** — 34 × 32.6 × 20.7 mm block, ~15 cc. Both heat-set insert bores in
their **real print orientations**, at the real wall thicknesses:

- Two horizontal 10-24 bores (Ø6.5 and Ø6.6 × 14 deep) entering opposite ends of a block
  drawn at the tube plate's own 12.7 mm thickness. **Axis parallel to the layers** — the
  bore is radial in the real part, so it prints as an unsupported round hole with only
  3.1 mm of roof over it. It is the one bore in the design whose printed shape is not its
  drawn shape, and reproducing that orientation is the entire point of this coupon.
- Two vertical M3 bores (Ø4.0 and Ø4.1 × 6 deep) — axis *perpendicular* to the layers,
  which is also how they print in the real part — in an 8 mm rib, a centering post top in
  all the ways that matter to a melting insert.
- A solid **modifier** around each 10-24 bore, the same 12.3 mm wide block the tube plate
  carries, so the roof over the bore prints into 100 % infill here exactly as it does
  there. The block is 32.6 mm wide rather than 24 so those two regions stay islands in
  40 % gyroid instead of merging and printing the whole coupon solid. Present only in the
  **3MF** — the STL is geometry alone.

Print two spare `pocket_cap.stl` alongside; you need a printed disc to test the printed
counterbore.

## Slicing

**Use the same profile, the same spool and the same enclosure temperature you will use
for the plates.** A coupon sliced as a fast draft answers a question you are not asking:
wall count and flow set hole size, so a 3-wall coupon does not predict a 5-wall plate.
In particular, whatever XY hole compensation / horizontal expansion is in the profile
must be identical in both — if you change it later, the coupon is void.

- 0.4 mm nozzle, 0.2 mm layers, **flat on the bed**, no supports needed by either part
- Walls **5**, top/bottom **5**, 40 % gyroid — matching the tube plate. This is no longer
  a claim you have to keep true by hand: `COUPON_SLICE` in `test_coupon.py` *is*
  `PRINT["tube_plate"]`, an assertion pins it, and `build/3mf/coupon_*.3mf` carries these
  settings into the slicer for you
- ABS 250–255 °C, bed 100–110 °C, **enclosure closed, cooling 0–20 %**, 8–10 mm brim
- Do **not** scale the model, and do not let the slicer "fix" the 100.000 mm outline

Both parts fit one plate; call it roughly an hour and a half and 35 g. Put them near the
middle of the bed, not at the edge where the chamber is coolest.

**If the coupon warps, throw the results away and fix the enclosure first.** A lifted
corner distorts every pocket over it, and a plate printed under the same conditions will
warp too — with more leverage.

Let it cool fully off the bed before measuring. ABS keeps moving for a while; two hours
minimum, overnight is better, and measure at room temperature.

## Reading it

Work from the tight end toward the loose end and stop at the first rung that passes.
Measure with the real hardware, not with calipers — the pockets are hexagonal and the
question is functional.

1. **Shrink gauge.** Caliper the outline at mid-height (avoid the elephant foot), a few
   places along each edge. `shrink % = (100.000 − measured X) / 100`. Record it; it is
   the number that explains everything else, and it is worth having on paper the next
   time this printer prints something that has to fit.
2. **Nut row `N`.** Push a real 10-24 hex nut into each pocket. Accept the tightest rung
   that seats fully flat under firm thumb pressure or a light squeeze in smooth vise
   jaws, **without whitening or cracking the wall**, and that will not rotate by hand.
   That is the press value.
3. **Head row `H`.** Drop a 10-24 hex head in. This one is fitted with silicone already
   curing on the other side of the plate, so it must **fall in under its own weight** and
   sit flat — accept the tightest rung that does, with no more than a few degrees of
   rotational slop. That is the slip value.
4. **Knobs.** Both knobs capture rather than accept on a timer, so they take the press
   value from step 2, not the slip value from step 3. They are ~2 cc each; this is a cheap
   thing to be wrong about, unlike the plates — but see the thin-wall caveat at the end,
   because their pockets are not in a plate.
5. **Cap counterbore.** A printed `pocket_cap` must drop in with obvious slack. It is
   bedded in RTV and is *supposed* to be loose — if it is a nice fit, that is a defect.
6. **Landing pads (bed face).** A **#4** washer should drop into the Ø8.24 recess and sit
   flush or slightly proud, never rock. If only the Ø8.54 one takes it, the first-layer
   squish is eating the recess: either dial the elephant-foot compensation or open
   `mirror_plate()`'s `+ 0.15` to what worked.
7. **Spring seat and the two bolt holes. READ THIS RUNG.** It was skipped on the first
   coupon and it is the one that mattered: the tube plate went to the bed with its pull
   holes drawn nominal, and they printed at 0.19" — the bolt's own major diameter, zero
   clearance, no collimation range at all. Both holes are now drawn oversize by
   `HOLE_LOSS` so they *print* at Ø5.16 and Ø5.60.
   - Spring drops into the seat and does not bind.
   - A 10-24 slides through **both** holes under its own weight, with no thread drag.
   - **Caliper the Ø5.50 rung.** It must come off the bed at 5.16 ± 0.05. Smaller means
     `HOLE_LOSS` is low for this profile — raise it and reprint the coupon **before** the
     tube plate, because the plate is 5.5–7 h and this coupon is twenty minutes.
   A caliper on a Ø5 hole reads low; if you have a pin gauge or a 13/64" drill shank, use
   that instead and trust it over the caliper.
8. **Insert coupon.** Install a 10-24 insert in each horizontal bore with a soldering
   iron at 230–250 °C, going in slowly and square. Keep the bore that goes in square and
   holds; the difference between them is only 0.1 mm and heat-set inserts are forgiving,
   so if both work, **take the smaller** — 6.5 prints at 6.448 mm against ruthex's 6.4 mm
   recommendation, while 6.6 prints at 6.547 and *fails* the bore assertion in `verify()`.
   Then, in order:
   - **Flush at the mouth, never proud.** The bore mouth is on the plate's arc at
     r = 95.25 mm, which *is* `TUBE_ID/2` — no relief, no countersink. An insert standing
     proud holds the whole plate off the tube wall, and you would discover it while
     drilling in situ with the plate already in the tube. Straightedge or caliper depth
     blade. (The coupon's rim is flat; the plate's is convex with a 0.20 mm crown across
     the boss, so on the real part reference the arc, not a straightedge over the boss.)
   - **Caliper the roof, don't just look at it.** 2.80 mm over the seated insert against a
     2.6 mm minimum — 0.2 mm of margin. Measure the block over each bore and again 10 mm
     away; any difference is the roof lifting. Look for whitening or a split line along
     the crown, which ABS shows before it fails.
   - **Load it by tightening, not by pulling.** The cell is 3.0 lb, so each insert carries
     1.0 lb static and ~10 lb under the 10 g transport knock of §7 — and that arrives as
     *shear*, since the screws are radial while the weight acts along or across the tube.
     Tension is self-inflicted: a hand driver puts 50+ lb of preload on a 10-24 screw,
     five times the worst transport load, so **stripping it during assembly is the real
     failure mode**. Put a screw through a 1″ fender washer, tighten against the rim face
     as if it were the tube wall to the torque you will actually use, and watch for the
     insert turning. Back it off and re-check flushness: one that migrated 0.1 mm is
     telling you something.
   - **Then break it open.** The coupon is expendable and this is the only way to see
     whether the 100 % modifier region really materialised around the bore. Snap or cut
     through one bore: gyroid touching the insert means the modifier did not apply, and
     the minimum-wall assertion is measuring material that is not there.

   Same sequence for M3 in the rib — 1.95 mm of wall each side, as in a real post, so a
   bulge there is a bulge in a centering post.

## Feeding the answer back

Four call sites cut hex pockets, and `hex_prism()` takes a per-call `fit=`:

| Call site | Pocket | Wants |
|---|---|---|
| `tube_plate()` | captured 10-24 nut | press (step 2) |
| `mirror_plate()` | captured pull-bolt head | slip (step 3) |
| `push_knob()` | captured push-bolt head | press (step 4) |
| `pull_knob()` | captured 10-24 nut, 0.4 mm proud | press (step 4) |

**This has been done** — `FIT` is now `FIT_PRESS = 0.10` (nuts and both knobs) and
`FIT_SLIP = 0.20` (pull-bolt head), passed explicitly at every call site. The one
thing to watch if you touch them again: `verify()` uses the fit to check that a bolt head
passes through the cap bore and that the ledge under the cap survives, and that check is
about the *mirror plate* pocket, so it is given `FIT_SLIP`. Pointed at the wrong constant
it would still pass, and would be checking nothing. There is room — the ledge fails only
past about 0.63 mm, well beyond the top of this ladder.

After any change, re-run `python3 mirror_cell.py` and confirm all checks still pass.

Do **not** touch any tube-referenced dimension on the strength of the measured shrink.
The tube plate OD is drawn at nominal 7.500" deliberately, confirmed by a real test fit;
shrinkage is what supplies that fit. See the traps in [HANDOFF.md](./HANDOFF.md).

## Results — 2026-07-28, first coupon

| | Measured | Reading |
|---|---|---|
| Gauge X | 3.91″ = 99.31 mm (drawn 3.937″) | **0.69 % shrink** (0.56–0.81 at ±0.005″) |
| Gauge Y | 1.95″ = 49.53 mm (drawn 1.969″) | 0.94 % (0.69–1.19 at ±0.005″) |
| **10-24 nut, row N** | **0.10 rung: seats flat, will not rotate, no whitening** | `FIT_PRESS = 0.10`, **confirmed** |
| Hex head, row H | not tested — no 10-24 hex bolt on hand | `FIT_SLIP = 0.20`, **predicted, unverified** |

Both gauge readings sit in the 0.6–0.8 % band ABS was expected to shrink by, which is
the result that matters most: nothing about the design has to be re-thought. Take the X
number as the better one — it is twice the gauge length for the same ±0.005″ of reading
error, and at 0.01″ resolution that error is most of the spread between the two axes.
Measuring in mm, or on a caliper reading to 0.001″, would settle whether the difference
between X and Y is real anisotropy or just the last digit.

**Why 0.10 rather than the 0.25 placeholder.** Work the shrink through the pocket: a
pocket drawn at `AF + fit` prints at about `(AF + fit)(1 − S)`, so the clearance the nut
actually sees is `fit·(1 − S) − AF·S`. At S = 0.008 the 0.10 rung leaves ≈ 0.02–0.03 mm —
a snug, no-rock capture — and the printed pocket bears that out on all three acceptance
criteria at once: the nut seats flat, will not rotate by hand, and the wall shows no
stress whitening, so the pocket is not being wedged open. The old 0.25 placeholder
would have left ≈ 0.17 mm, and a captured nut with 0.17 mm of play can rock in its pocket
under the push bolt's reaction. The coupon paid for itself on this rung alone.

**Why the head pocket is not simply 0.10 too.** Same arithmetic on the smaller
across-flats: `AF·S` is 0.06 mm rather than 0.08, so the head pocket comes out about
0.01 mm looser than the nut pocket at the same rung — nowhere near enough to turn a
press fit into something a bolt head falls into on its own. The pull-bolt head is fitted
while the silicone is curing, so it must drop in; 0.20 is predicted to leave ≈ 0.13 mm,
about 2° of rotational slop, which the pull knob takes out anyway. **Confirm it on row H
before printing the mirror plate** — one 10-24 hex bolt settles it, and six of them are
on the buy list regardless.

Still unread on this coupon: cap disc, landing pads, spring seat.

## Results — 2026-07-31, the clearance hole, read off the tube plate instead

**The rung above went unread, and the tube plate paid for it.** With the plate printed and
being assembled, the push bolts had to be forced through their holes. Measured: **0.19"
(4.83 mm)** against Ø5.159 drawn — the bolt's own major diameter, **zero clearance.**

Linear shrink accounts for 0.04 mm of the 0.33 mm lost. The other **0.29 mm** is what a
small round hole gives up to the slicer: chords cutting inside the true circle, and an
inner perimeter laid on a tight radius where it over-fills. Both scale with extrusion
width, not with diameter, so it is an offset — `HOLE_LOSS = 0.30`, rounded up because a
hole 0.01 mm too big costs nothing here and one 0.01 mm too small cost a 7-hour reprint.

**It applies to round holes only, and the same coupon proves it.** The hex pockets
measured clean at `FIT_PRESS = 0.10`, whose entire clearance is 0.02–0.03 mm. Had they
lost 0.29 mm as well they would have been a quarter-millimetre of interference and no nut
would have entered, let alone seated flat with no whitening. Flat walls have neither
chords nor tight radii. `PRINT_SHRINK` was never wrong; it was just not the whole story.

The real cost was not the fit. It was the **collimation range**: `pull_bolt_tilt()`
reported ±1.42° for a plate whose holes could not let a bolt lean at all. Every step of
that arithmetic was correct and rested on an unstated assumption that a bolt fits the
hole. `verify()` now asserts it — the cheapest check in the file, and the last one anybody
thought to write.

## Results — 2026-07-29, insert coupon

**Printed and both 10-24 inserts installed. Everything checked passed.** That clears the
last geometric unknown in front of the tube plate: the bore diameter is right, the roof
holds a seated insert, and `INSERT_BORE_D = 6.5` stands as drawn — the 6.6 rung was not
needed, which is the good outcome, since 6.6 would have failed the bore assertion.

This was the first print of the coupon **with the `insert_solid` modifiers**, so it is also
the first evidence that the reinforcement scheme works in practice and not just in the
file. The bores were printed in their real orientation — axis parallel to the layers,
unsupported round hole, 3.05 mm of roof — which is the condition the tube plate will be in.

| | Result |
|---|---|
| Ø6.5 bore | insert seated, **kept** — `INSERT_BORE_D` unchanged |
| Ø6.6 bore | also seated; not needed, and out of tolerance against ruthex's 6.4 mm |
| Roof over the bore | held |
| M3 bores in the rib | held |

**Not done: sectioning the coupon.** Breaking a bore open is the only way to confirm the
100 % modifier region actually materialised around it rather than leaving gyroid against
the insert, and the minimum-wall assertion assumes it did. The coupon is expendable and the
inserts are cheap; worth doing before the tube plate rather than after. Until then, treat
the modifier as verified *in the file* (`verify()` reads the meshes back out of the zip)
but not verified *in the plastic*.

**What this coupon does not test.** Every pocket here sits in a 6 mm plate with material
all around it. Both knobs put the same pocket inside a **2.2 mm wall**
([ADR-0002](./docs/adr/0002-both-rear-controls-are-printed-knobs.md)), where a press can
bulge the wall instead of gripping. Print one `pull_knob` — the worse case, bigger nut,
same wall — and press a nut into it before committing to six.

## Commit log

2026-07-28 Initial commit: 6" mirror cell, verified build123d model
    A one-off 3-point primary mirror cell for a 6" f/7.33 Newtonian, 3D
    printed in black ABS with 10-24 hardware. Designed in a single session;
    nothing has been printed from it yet.
    - mirror_cell.py build123d model. All dimensions named at the top;
    71 assertions run before it exports anything.
    - index.html browser viewer: 13-step assembly walkthrough plus an
    explode/inspect mode, driven by build/assembly.json
    so the instructions cannot drift from the geometry.
    - mirror-cell-spec.md the design and, more importantly, why.
    - CONTEXT.md glossary. Tube plate, Mirror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
    [90866A011_NO THREADS_Zinc-Plated Steel Wing Nut.STEP]
2026-07-28 Test coupons, measured FIT, and STEP downloads in the viewer
    Resolves the project's one blocker. FIT was a 0.25 mm placeholder for hex-pocket
    clearance that no assertion could verify, because ABS shrinkage is a property of
    the printer and the profile, not of the geometry.
    test_coupon.py builds two ABS coupons from mirror_cell's own hex_prism() at its
    own depths, so they cannot drift from the parts they stand in for:
    coupon_fit a ladder of six clearances at both hex sizes, plus the cap,
    landing-pad (on the BED face, where elephant foot lands),
    spring-seat and clearance-hole fits. The outline is drawn at
    exactly 100.000 x 50.000 so the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
2026-07-28 Rear controls become two printed knobs; fix the spring preload
    The push knob and the wing nut sit on one station ray 19.05 mm apart and
    overlapped by 7.06 mm radially. The old escape was axial: 2" push bolts to
    drop a 30 mm knob below the wing nut. That clearance depended on bolt length
    AND on where the adjusters were set -- advancing the push screw carries its
    knob back into the wing nut's z-band -- and nothing checked the second
    dependency, because with the knob 22.9 mm out it never bound.
    Both rear controls are printed knobs now (push ø16, pull ø18 capturing a plain
    hex nut), sized to clear each other RADIALLY by 2.05 mm. A radial clearance
    between two circular knobs on fixed bolt circ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
2026-07-28 Show the assembled cell in a transparent tube stub, with a fan
    The final step of the walkthrough now drops the cell into a stub of the
    sonotube -- 7.500" ID, 0.125" wall, 7.750" OD -- reaching 3.65" rearward of the
    tube plate's mid-plane and 2" above the mirror's front surface, 7.94" overall.
    It is drawn in the viewer from four numbers in assembly.json rather than loaded
    as an STL, since it is a plain annulus, and rendered at 13% opacity with
    depthWrite off so it never occludes what it wraps.
    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
2026-07-29 Push knob is blind behind its pocket
    The bore did nothing. The shank leaves through the pocket's own opening -- the
    knob's plate-facing face -- so the ø5.16 hole behind it was only a hole out the
    back, invisible at ø30 and an eyesore at ø16. Blind means a pressed head is in
    for good, which is the intent for a form-fit capture.
    Not to be confused with the pull knob's identical-looking bore, which is real
    work: tightening drives the bolt end into it. Recorded as a trap, along with
    why the push pocket cannot simply be flipped to face rearward -- the body would
    have to reach 14 mm forward of the head into 10.16 mm of standoff and would
    bury itself in the tube plate.
    105 checks. The new one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
2026-07-29 Generate an annotated bill of materials, downloadable from the viewer
    A BOM is exactly the document that rots: it is read once, at the shop counter,
    long after the geometry moved. So nothing in this one is typed. bom() counts the
    printed quantities off the same instance lists the picture uses, reads every
    hardware dimension out of the parameters, and carries a line of WHY on each row --
    machine screws not cap screws, springs by geometry not by rate, fender washers on
    the OUTSIDE of the tube.
    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
2026-07-29 Commit BOM.md as a checked snapshot of the generated buy list
    build/ is gitignored, so until now the repo carried no readable buy list at all --
    you had to run the model to see one. mirror_cell.py now writes the same Markdown to
    BOM.md at the top level, and verify() checks that copy line by line against the rows
    it just computed: quantity, item and annotation. A stale snapshot fails the build
    rather than quietly sending someone to the shop with last month's quantities.
    Line for line rather than byte for byte, because the snapshot carries part volumes
    and verify() does not build the solids.
    Seen to fail both ways it can rot: a quantity left behind (clip 3 -> 4) and an
    annotation edited by h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
2026-07-29 Pin the insert wall, and stop the BOM check deadlocking its own fix
    Six things, all from reviewing what was still genuinely open before finalizing.
    Mirror plate thickness is annotated at the constant. It read "OPEN ITEM:
    proposed, not verified" while the spec recorded it as resolved. It is
    resolved, and it is pinned by BOLT LENGTH, not stiffness: the pull-bolt head
    is captured in this plate with its nut outside, so thickness comes straight
    off the thread the nut runs on. At 0.500" with the same 1.5" bolts the thread
    runs out +0.23 mm past nominal instead of +3.41 mm. 1.625" pull bolts restore
    it but break the one-length rule; 1.75" overshoots and the spring goes slack
    first. All three were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
2026-07-29 Landing pads that stop the bolt, and 3MFs that carry their own settings
    Three strands, all uncommitted until now. 163 checks pass, up from 121.
    THE LANDING PADS WERE NOT DOING ANYTHING. They were #10 washers under #10
    bolts, and a #10 washer's bore IS free-fit clearance for a #10 bolt -- so the
    push-bolt tip passed through with 0.166 mm to spare and bore on the plastic
    floor of the recess over 18 mm^2, a SMALLER area than the flat plate would
    have given it. The recess was actively making the thing it existed to
    prevent worse. Now #4 washers: 0.125" bore against a 0.190" bolt, leaving a
    5.3 mm^2 contact annulus. A #6 leaves 0.9 mm^2 -- a 0.07 mm ring, knife-edge
    on the bore rim -- and verify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
2026-07-29 The insert coupon had no insert bores
    Found by asking why the coupon's hole ran perpendicular to the layers when
    the tube plate's runs parallel. It did not: the coupon had no 10-24 bores at
    all, and the only holes in it were the two vertical M3 ones.
    Both radial cuts were aimed outward from the rim. The block spans x = +/-17
    and the cuts ran from +/-17 to +/-31, entirely outside the solid, removing
    nothing and leaving a perfectly valid part. Volume was 12128.6 mm^3 against
    12128.6 mm^3 computed for block + rib - M3 bores alone.
    All five insert checks passed, because all five were arithmetic on constants:
    roof depth, bore spacing, bore depth against block length. Every number was
    correct. N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
2026-07-29 Ask the fit coupon's solid whether its features exist
    The insert coupon shipped without its bores because every check about them
    was arithmetic on constants. The fit coupon was audited for the same
    weakness and has it, though not the bug: all nineteen of its features are
    genuinely cut -- probed and confirmed -- but only three of its fourteen
    checks touched the solid, and none asked whether a feature existed. A plain
    slab would have passed everything except the two bounding-box checks, and
    those only see the outline.
    Now checked, per feature: twelve hex pockets across both rows and all six
    rungs, the punch-out hole under each, the cap counterbore, both landing-pad
    recesses on the bed face, t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
2026-07-29 Write down where the collimation range comes from
    The tilt range was never a designed number and was not recorded anywhere.
    It falls out of BOLT_CLEAR_D, the stock free-fit clearance for a #10 screw:
    0.166 mm per side over an 11.7 mm guiding length (the 1/2" tube plate less
    the 1.0 mm spring seat, which is Oe9.8 and constrains nothing).
    as printed, at 0.8% shrink: +/-1.42 deg, 85 arcmin
    +/-2.12 mm at one station
    +/-1.89 mm at the mirror edge
    as drawn: +/-1.62 deg
    Half-angle, and the cone is symmetric: all three pull bolts share the mirror
    plate's normal, so each tilts by the same angle whichever way the p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
2026-07-29 Bracket the tilt budget in verify()
    pull_bolt_tilt() computes the collimation half-angle from the geometry --
    bolt major diameter against the printed clearance hole over an 11.7 mm guide
    -- by bisecting d/cos t + L*tan t. Defaults to AS PRINTED, because the hole a
    bolt actually leans in is the shrunk one.
    Three checks, failing for three different reasons:
    budget >= TILT_NEEDED the range the cell must PROVIDE. Typed, because
    it is a requirement, not a measurement: 0.5 deg
    absorbs a tube drilled a couple of mm out of
    square over the 85.7 mm station lever.
    budget < TILT_MAX the swing envelope m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
2026-07-29 Insert coupon read and passed; the tube plate is cleared to print
    Printed 2026-07-29 with the insert_solid modifiers in place, both 10-24
    inserts installed, everything checked held: bore diameter, the 3.05 mm roof
    over the radial bore, the M3 bores in the rib.
    INSERT_BORE_D = 6.5 stands as drawn. The 6.6 rung also took an insert but was
    not needed, which is the good outcome -- 6.6 prints at 6.547 mm, 0.147 mm off
    ruthex's recommended hole against a 0.1 mm tolerance, and would have failed
    the bore assertion.
    This was the first print carrying the modifiers, so the reinforcement scheme
    is now confirmed in practice and not only in the file.
    Recorded as a Results section in TEST-COUPON.md besi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
2026-07-29 Correct the tube plate's print time: 5.5-7 h, not 3.5
    Measured this session by slicing build/3mf/tube_plate.3mf -- 7 h at the
    part's own overrides (5 walls, 180 mm/s inner wall) and 5.5 h on the standard
    quality preset. The 3.5 h figure predates the settings work and would have
    had someone start a 7 h print on a 3.5 h plan.
2026-07-31 Bolt holes are drawn oversize, because round holes do not print nominal
    MEASURED on the printed tube plate, 2026-07-31: the pull holes, drawn 5.159,
    came off the bed at 0.19" -- 4.83 mm, the bolt's own major diameter. Zero
    clearance. The push bolts had to be forced through during assembly, which is
    how it was found, but the fit was the cheap half of the damage: at that
    diameter pull_bolt_tilt() is 0.00 deg, so the plate had NO collimation range
    at all while the model reported +/-1.42 deg.
    Linear shrink accounts for 0.04 mm of the 0.33 mm lost. The other 0.29 is
    what a small round hole gives up to the slicer: chords cutting inside the true
    circle, and an inner perimeter laid on a tight radiu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
2026-08-05 Refresh the counts in HANDOFF.md against what the checks now report
    171 model assertions, not 166; test_coupon.py is 103 checks, not 101;
    16 commits, not one. Two part volumes had drifted a rounding step.
    The "nothing has been printed" line is rewritten rather than renumbered:
    both coupons have been printed and read since it was written, but no cell
    part has, which is the claim it was making.
2026-08-05 Build the 8" cell from the same file, by --aperture
    An 8.000" x 1.330" mirror in a 10.000" ID tube, as a CELLS entry rather than a
    branch or a second module. Three numbers change; the bolt circles, both plate
    outlines and the post height follow from them. All the hardware is untouched --
    10-24 throughout, the same inserts, knobs, pads and measured fits -- so the
    coupon work carries over, and TUBE_PLATE_T holds the insert roof at 2.80 mm and
    the collimation range at +/-1.62 deg in both cells.
    A fork was the alternative and was rejected: the value here is in the 171
    assertions, several of which were only trusted after being watched to fail, and
    two copies would let a check repaired on one cel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
2026-08-05 The viewer's heading is read from the model, not typed into the HTML
    The page rendered the 8" cell under a 6" heading: ?cell=8 switched the geometry,
    the labels and the downloads, but the <title>, the <h1> and the subtitle were
    static text and nothing updated them. The one part of the viewer still carrying
    a dimension in the HTML was the part that SAYS what it is showing.
    All three now come off assembly.json with everything else, so they cannot
    disagree with the parts on screen.
    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
2026-08-30 Show the viewer in the README, rather than only describing it
    The page is the fastest way to understand what the cell is, and it needed a
    server and a build directory before anyone could see it. The screenshot is
    step 12 of the 6" sequence: the finished cell, out of the tube, with the
    sequence list beside it.
    Claude-Session: https://claude.ai/code/session_014xwfqSzLV4X2nuUP9PQ7Pe
2026-09-04 Force solid infill around every through hole, by generated modifier
    Every part sliced at under 100% infill now carries one hole_solid modifier
    per through hole: a cylinder bored radius + 2 mm, clamped to the part's
    envelope. The modifier is found from the solid -- cylindrical faces grouped
    coaxially, then open-at-both-ends and enclosed-in-material tests, so blind
    bores and the knobs' flute cutters are left alone -- and the round trip is
    checked against expected_hole_mods(), constants rather than the detector.
    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
2026-09-05 Publish the viewer to GitHub Pages, built by Actions
    The build directories are gitignored, so the page has nothing to fetch from the repo as
    committed. The workflow runs the exporter for both cells and the coupons, re-runs --check
    so a stale BOM snapshot fails the deploy rather than publishing over it, and serves the
    tree as built -- assembly.json already names the download paths with their build/ prefix.
    Claude-Session: https://claude.ai/code/session_015VjfuPXtv8EusjGg1XnAgH
2026-09-11 Take the mirror's thickness from --mirror-thickness, for the blank you have
    CELLS assumes 1.000" at 6" and 1.330" at 8", but real 8" blanks run from 1"
    Borofloat to 1-3/8" plate. The flag (inches, or MIRROR_CELL_MIRROR_T) replaces
    the entry's mirror_t and nothing else; post height, the tube stub and the
    moving mass follow it. The stated moving_n shifts by the glass alone, so the
    mass check still catches a plate that got heavier.
    A variant builds into build-<aperture>-t<thickness>/, which the viewer already
    opens as ?cell=8-t1.375, and writes no committed snapshot -- BOM.md, BOM-8.md
    and CI are untouched. A new check refuses any blank that sags (R^4/t^3) more
    than the CELLS blanks do, since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
2026-09-15 Offer the whole cell as one dated zip, from the same list the panel shows
    Every printed part's STEP and 3MF in a single file, named for the cell and the
    day it was built -- once a zip has been mailed to somebody, the filename is all
    that still says which cell it holds and how old it is.
    The contents come from the download list rather than from PARTS, so the zip
    cannot hold a file the viewer does not offer nor miss one it does, and four
    assertions say so. It is written after the 3MFs round-trip, because a copy of
    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
2026-09-19 Build the collimation bolts as 10-24 or 1/4-20, from one file
    --bolts selects the six push/pull bolts and their nuts; everything the fastener
    touches derives from the BOLTS entry -- the two clearance bores, the hex
    pockets, the knob diameters that hold them, the cap bore the taller head has to
    pass through, and the mirror plate's thickness, which keeps a sound floor under
    it. At 10-24 every derived value reproduces the constant it replaced, bit for
    bit. The tube-mount heat-set inserts stay 10-24 in every build: a 1/4-20 ruthex
    insert is 8.7 mm across and cannot keep its 3.3 mm wall in a 0.500" plate, and
    giving it one would re-open the axial stack for a screw that carries no
    adjustment. See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
